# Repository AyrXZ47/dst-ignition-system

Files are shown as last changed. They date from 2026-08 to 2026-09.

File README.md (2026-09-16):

# 🚀 DST Ignition System




A solid-state, remote ignition system designed for experimental rocketry. Built for the Dragons Space Team to safely and reliably ignite rocket motors (like Estes Viking) using electronic matches.

## 🧠 System Architecture
* **Microcontroller:** Raspberry Pi Pico (RP2040)
* **Firmware:** Rust 🦀 with Embassy — **planned, not implemented yet** (see [Hardware status](#-hardware-status))
* **Telemetry & Comms:** LoRa (SX1278 RA-02, single transceiver — TX/RX role is firmware-side, half-duplex)
* **Power Switching:** Logic-Level N-Channel MOSFET (AOD4184A)

## 📂 Repository Structure
* `/hardware/`: KiCad project files (Schematics and PCB layouts).
* `/src/`: Rust source code for the RP2040 firmware.
* `/docs/`: Pinout diagrams, component datasheets, and operation manuals.

## 🛠️ Getting Started
### Firmware (Rust)
⚠️ **Not available yet.** The `src/` directory is empty: the Rust/Embassy firmware is planned but has not been written. The steps below are reserved for when it lands:

1. Install Rust and the `thumbv6m-none-eabi` target:
   `rustup target add thumbv6m-none-eabi`
2. Install `elf2uf2-rs` for easy flashing:
   `cargo install elf2uf2-rs --locked`
3. Build and run: `cargo run --release`

### Hardware
Open the project in KiCad 10.x (KiCad 9.x also fine) located in the `/hardware/` directory.

## 📋 Hardware status

Schematics and PCB live in `/hardware/Kicad/ignition-system/`. Current status
(wave 3, in progress — see [`docs/design-notes.md`](docs/design-notes.md) for
the full design reference):

* **Schematic:** RP2040 (Pico) + TP4056 Li-ion charger (TEMP via external NTC 10k B3950, TH1) + AOD4184A N-MOSFET ignition switch + SX1278 RA-02 socket (2× 1×08 headers: SPI + control rows) + I2C display + status LEDs + master power switch SW3 (battery → SW3 → VSYS; the pack charges with the board off). ERC: 0 errors / 0 warnings.
* **PCB:** placement in progress, **not routed** (agentes solo verifican con kicad-cli). DRC findings pending wave-3 fixes; see design-notes §5.
* **Firmware:** `src/` is empty; no Rust/Embassy code exists yet.
* **Next:** wave 2 SPICE validation of the MOSFET gate margin (3.3V vs Vto 2.61V).

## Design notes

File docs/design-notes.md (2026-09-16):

# Design Notes — DST Ignition System

> Referencia de diseño del sistema de ignición remota para cohetería
> experimental (Dragons Space Team).
> Fuentes: netlist exportado de `hardware/Kicad/ignition-system/ignition-system.kicad_sch`
> (2026-08-14, `kicad-cli sch export netlist`), `DRC.rpt`, y decision log en
> `.workflow/plan.md`. Estado: **wave 1 en curso** (fixes del esquemático en
> manos del humano, ver §3).

## 1. Topología

Sistema de ignición por MOSFET de lado bajo, alimentado por LiPo 1S y con
enlace de radio LoRa/nRF24:

```
                ┌────────────────────────────────────────────────┐
 USB ◄────────► │ Raspberry Pi Pico (RP2040)                     │
                │                                                │
                │  GPIO13  BTN_FIRE  ← SW1 (botón)               │
                │  GPIO15  IGNITION_GATE → R11 220Ω → G AOD4184A1│
                │  GPIO10/11/12 LEDs LINK / MODO / ARMADO        │
                │  GPIO26  ADC_Bateria ← divisor R5/R6 (10k/10k) │
                │  GPIO4/5 I2C (SDA/SCL) → Display1              │
                 │ GPIO16-19 SPI + GPIO20/21 → socket RA-02       │
                └───────┬─────────────────────────────────┬──────┘
                        │ VSYS (batería)                  │ 3V3
                ┌───────▼────────┐               ┌────────▼─────────┐
                │ TP4056 (carga) │               │ Display1 (I2C)   │
                │ CE → VBUS      │               │ 1x04, 2.54mm     │
                 │ TEMP → TH1 NTC │               └──────────────────┘
                 └───────┬────────┘
                         │ BATP (celda + BAT del TP4056)
                 ┌───────▼────────┐               ┌──────────────────┐
                 │ InBatt1 (JST)  │               │ AOD4184A1        │
                 │ LiPo 1S(PCM)   │               │ D ◄─ IGNITOR1.2  │
                 └───┬────────────┘               │ G ◄─ R11 ← GPIO15│
                     │ SW3 (SPDT)                 │ S → GND (low-side│
                     └─► VSYS ──► SW2.1/2.2 ──► IGNITOR1.1 (e-match)
                                       IGNITOR1 = terminal 5.0mm (1x02)
```

Flujo de disparo: `BTN_FIRE` (SW1) → GPIO13; firmware activa `IGNITION_GATE`
(GPIO15) → R11 220Ω → gate del AOD4184A1 → conduce → cierra el circuito del
ignitor (IGNITOR1) contra GND. El flujo de potencia de la placa: celda
(InBatt1) → nodo BATP (compartido con el pin BAT del TP4056) → SW3 → VSYS.
SW3 es el switch maestro de la placa: abierto = Pico/LEDS/divisor/ignitor
sin tensión (consumo ~0), cerrado = normal; la carga funciona con la placa
apagada (VBUS del pin 40 del Pico → TP4056 → BATP → celda, sin pasar por SW3).
SW2 (SPDT) conecta la línea del ignitor a VSYS (ON) o la ata a GND (seguro/descarga, línea sin fuente detrás).

## 2. Mapa de pines RP2040 (Raspberry Pi Pico)

Fuente: netlist exportado del esquemático (pad → net). Los GPIO se numeran
según el pinout estándar del Pico.

| Pad Pico | GPIO | Net | Función |
|---|---|-----|---|
| 6 | GPIO4 | SDA | Display I2C |
| 7 | GPIO5 | SCL | Display I2C |
| 14 | GPIO10 | LED_LINK | LED azul de enlace (R1 330Ω) |
| 15 | GPIO11 | LED_MODO | LED amarillo de modo (R2 330Ω) |
| 16 | GPIO12 | LED_ARMADO | LED rojo de armado (R3 330Ω) |
| 17 | GPIO13 | BTN_FIRE | Botón de disparo (SW1) |
| 20 | GPIO15 | IGNITION_GATE | Gate del MOSFET vía R11 220Ω |
| 21 | GPIO16 | MISO | SPI socket LORA RA-02 (fila LORA-Sx1278(B)) |
| 22 | GPIO17 | NSS | SPI CS (LORA-Sx1278(B)) |
| 24 | GPIO18 | SCK | SPI (LORA-Sx1278(B)) |
| 25 | GPIO19 | MOSI | SPI (LORA-Sx1278(B)) |
| 26 | GPIO20 | RST | Reset (LORA-Sx1278(A), fila de control) |
| 27 | GPIO21 | DIO0 | IRQ (LORA-Sx1278(A)) |
| 31 | GPIO26/ADC0 | ADC_Bateria | Medición de batería (divisor R5/R6) |
| 3, 8, 13, 18, 23, 28, 38 | — | GND | Tierra |
| 36 | — | 3V3 | Alimentación 3.3V |
| 39 | — | VSYS | Alimentación del Pico (batería) |
| 40 | — | VBUS | USB; alimenta el CE del TP4056 |

Sin conectar (disponibles para ola 2/3): GPIO0-3, GPIO6-9, GPIO14, GPIO22,
GPIO27/ADC1, GPIO28/ADC2, AGND, ADC_VREF, RUN, 3V3_EN.

Nota radio: LORA-Sx1278(A) y LORA-Sx1278(B) son una ÚNICA radio — el SOCKET
físico del módulo SX1278 RA-02 (2 filas de 8 agujeros, un borde por cara del
módulo de 17×16 mm). Fila A = control (GND, GND, 3V3, RST, DIO0); fila B =
SPI (NSS, MOSI, MISO, SCK); DIO1–DIO5 quedan sueltos sin conectar. El rol
TX/RX es puro firmware: transceptor half-duplex, un módulo por placa.

## 3. Decisiones de diseño

Del decision log de `.workflow/plan.md` (wave 1):

- **CE del TP4056 → VBUS (pin 8), no al net "VCC".** El net VCC no tiene
  fuente (ERC `power_pin_not_driven`). El pin 8 queda alimentado por VBUS, que
  viene del USB del Pico. *Estado: fix del humano en curso (GUI).*
- **TEMP del TP4056 (pin 1) va a GND a través de TH1** (NTC 10k B3950, header
  1x02; el NTC se pega a la celda, V lo confirma para 2026-09-15b). Revoca la
  nota wave 1 de "TEMP→GND": TEMP recupera su función térmica (ventana
  ≈ 0–45 °C); la protección eléctrica de la celda vive en el PCM integrado.
- **Labels DIO1-DIO5 eliminados.** Colgaban sin destino en el esquemático; si
  se necesitan en ola 2/3, se re-añaden con propósito concreto.
- **Human-in-the-loop como modelo de trabajo** (adaptación de AGENTS.md a
  hardware): el humano edita KiCad en GUI; los agentes planifican, verifican
  con `kicad-cli`, documentan y simulan. Los fixes de wave 1 los aplica el
  humano (~5 min de clics).
- **SW3 = switch maestro en serie entre BATP y VSYS** (nodo BATP: InBatt1.1 +
  pin BAT del TP4056). La carga funciona con la placa apagada (VBUS del pin 40
  del Pico → TP4056 → BATP → celda, aguas arriba del switch); con SW3 abierto
  el consumo es ~0. El pin suelto del SPDT queda sin conectar (nunca a GND:
  un interruptor de potencia a tierra cortocircuita el pack al accionarlo).
  Hay un PWR_FLAG en VSYS (anotación KiCad para satisfacer el ERC del switch
  de potencia, sin efecto eléctrico).
- **Disparo low-side**: el ignitor (J1) va entre la alimentación conmutada por
  SW2 y el drenador del MOSFET; fuente a GND. Pull-down R7 10k en el gate.
- **Divisor de batería**: VSYS → R5 10k → ADC_Bateria → R6 10k → GND.

## 4. BOM preliminar

Extraído del netlist exportado (29 referencias, 2026-09-16). Pendiente de confirmar
valores de display/módulos con el humano.

| Ref | Valor | Footprint | Función |
|-----|---|---|---|
| RaspberryPi_Pico1 | Raspberry Pi Pico (RP2040) | Module: Pico común | MCU |
| ModuloDeCarga1 | TP4056-42-ESOP8 | SOIC-8-1EP 3.9x4.9mm | Cargador Li-ion 1S |
| AOD4184A1 | NMOS (Vto≈2.61V, Ron≈5.8mΩ) | TO-252-2 | Interruptor de ignición |
| C1, C2 | 10µF | 0805 | Desacople |
| R1, R2, R3 | 330Ω | 0805 | LEDs LINK/MODO/ARMADO |
| R4 | 2.2kΩ | 0805 | PROG del TP4056 |
| R5, R6 | 10kΩ | 0805 | Divisor ADC_Bateria |
| R7 | 10kΩ | 0805 | Pull-down del gate |
| R8, R9 | 1kΩ | 0805 | LEDs STDBY/CHRG del cargador |
| R11 | 220Ω | 0805 | Serie al gate |
| BLED1, YLED1, RLED1 | LED | 0805 | Estado: enlace/modo/armado |
| CHRG1, STDBY1 | LED | 0805 | Estado de carga |
| Display1-SSD1306 | SSD1306 (conector 1x04) | PinHeader 2.54mm | Display I2C |
| InBatt1 | Conector 1x02 | JST PH 2.0mm | Batería LiPo 1S (≥500mAh: pulso de ignición ~2.7A) |
| IGNITOR1 | Terminal 1x02 | Screw_Terminal_01x02 5.0mm | Ignitor/e-match |
| LORA-Sx1278(A), (B) | Conector 1x08 | PinHeader 2.54mm | SOCKET del módulo SX1278 RA-02: fila control (A) + fila SPI (B) — 1 radio por placa |
| TH1 | NTC 10k B3950 | PinHeader 1x02 | Sonda térmica del TEMP del TP4056 (pegada a la celda) |
| SW1 | Pulsador | PinHeader 1x02 | BTN_FIRE |
| SW2 | SPDT | PinHeader 1x03 | Selector de ignitor: VSYS / GND |
| SW3 | SPDT | PinHeader 1x03 | Switch maestro de la placa (BATP ↔ VSYS) |

## 5. Estado del PCB

`hardware/Kicad/ignition-system/ignition-system.kicad_pcb` (KiCad 10.0):

- **Colocación en progreso** (humano, GUI, 2026-09-16): footprints colocados
  en tablero; sin conectar.
- **Ruteo: pendiente** (lo hace el humano en la GUI; los agentes solo
  verifican con `kicad-cli pcb drc`).
- **DRC 2026-09-16: 98 hallazgos** = 32 violaciones + 66 pads sin conectar
  (consecuente con un board sin rutear). Desglose de violaciones:
  `drill_out_of_range` ×6, `hole_clearance` ×8, `hole_to_hole` ×3,
  `copper_edge_clearance` ×2, `shorting_items` ×6, `items_not_allowed` ×2,
  `silk_over_copper` ×31, `silk_overlap` ×15, `silk_edge_clearance` ×10,
  `solder_mask_bridge` ×6, `lib_footprint_mismatch` ×9.
  ⚠️ Las 6 `drill_out_of_range` del TP4056 REGRESARON: el árbol integrado
  tiene `"min_through_hole_diameter": 0.3` (línea 161 del .kicad_pro) —
  el fix de T6 (0.2) se revirtió en la integración/fusión del .kicad_pro.
  Reportado a V; corregir con el humano en GUI antes de seguir el ruteo.
- ERC: **0 errores / 0 warnings** (2026-09-16, tras H7b/H8/H9 del humano).

## 6. Pendientes y riesgos

- **Margen de gate del AOD4184A1**: Vto≈2.61V contra 3.3V lógicos → Vgs−Vto
  ≈ 0.7V. Validar por SPICE en ola 2 (modelo en `hardware/Kicad/ignition-system/Local Spice/AOD4184A.lib`);
  si no conduce suficiente, driver de gate o MOSFET con Vto menor. También:
  slew rate con R11=220Ω y picos en el pull-down R7.
- **Switch maestro SW3 + carga**: BATP (celda + pin BAT del TP4056) → SW3 →
  VSYS; la carga funciona con la placa apagada (VBUS pin 40 → TP4056 → BATP,
  sin pasar por SW3); con SW3 abierto el consumo del sistema es ~0 (reemplaza
  al viejo "BAT+ (VSYS)" directo). Colocar cerca del borde, aparte del
  conector InBatt, con huella accesible de mano enguantada.
- **NTC TH1**: pegar físicamente la sonda B3950 a la celda (cinta Kapton) y
  ruta corta InBatt→TH1 en el ruteo; ventana térmica ≈ 0–45 °C.
- **Firmware**: `src/` está vacío; el Rust/Embassy prometido en el README aún
  no existe (ver README, §Estado del hardware).
- **Ignitor/e-match — RESUELTO 2026-09-02 (medido, lote n=10)**: R_min/R_typ/
  R_max = **0.8 / 0.93 / 1.1 Ω** (2 multímetros, spread ≤0.3Ω, lote
  consistente). R_wire del cableado no medido: estimado **0.2Ω** conservador.
  Fase B destructiva: 4/4 ignitores disparados con pila 3V vía amperímetro;
  rango 200mA en OVERLOAD → I_fire > 200mA real (la lectura "0.01A" del rango
  10A se descarta como artefacto de display: el burst dura ms, el DMM muestrea
  ~3/s; a 10mA con 0.93Ω habría solo 0.1mW — físicamente imposible).
  **Chequeo de margen**: `I_worst = 3.3 / (R_max + R_wire + 0.034)` =
  3.3 / (1.1 + 0.2 + 0.034) ≈ **2.47A ≥ 1.1A** (margen 2.25×). Nominal
  3.6V → 2.70A. P ignitor ≈ 6.7W por pulso; P MOSFET ≈ 0.21W por pulso
  (trivial para DPAK). **Cierra la condición del REPORT.md de wave 2:
  veredicto (a) CONFIRMADO con datos reales** — AOD4184A se queda, sin driver
  ni cambio de MOSFET. Fuente: decision log de `.workflow/plan.md`
  (entrada 2026-09-02).
- **Radio — RESUELTO 2026-09-15**: es LoRa SX1278 RA-02. No hay dos radios:
  LORA-Sx1278(A)/(B) son el socket físico del módulo (2 filas de 8); el rol
  TX/RX es puro firmware (transceptor half-duplex, un módulo por placa).
  DIO1–DIO5 del módulo quedan sueltos (sin conectar en el socket).
- **Display — modelo confirmado (2026-09-01)**: SSD1306 I2C sobre conector
  1x04; queda solo confirmar si el conector 1x04 basta (el 5º pin del
  SSD1306-A es VCC extra, opcional).

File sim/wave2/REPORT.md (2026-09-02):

# REPORT — Validación SPICE del disparo del ignitor (Wave 2 · Executor 3)

**Fecha:** 2026-09-01 · **Simulador:** ngspice-45 (`/run/current-system/sw/bin/ngspice`)
**Netlist:** `sim/wave2/ignition-sim.cir` (autocontenido, modelo VDMOS inline)
**Reproducir:** `bash sim/wave2/run.sh` → salidas en `sim/wave2/out/` (log + `.raw` por caso)

## Veredicto: **(a) OK para rutear con el AOD4184A**

El AOD4184A conduce el ignitor con holgura a Vgs≈3.3V en todos los casos
simulados, incluido el peor caso (LiPo descargada 3.3V + ignitor 2Ω):

| Caso | Ignitor | VSYS | Id disparo | Vds | Rds(on) eff. | P MOSFET | Criterio ≥1.5A |
|---|---|---|---|-----|---|---|---|
| 1 (nominal) | 1.5Ω | 3.6V | **2.347 A** | 79.5 mV | 33.9 mΩ | 0.19 W | ✓ +0.85A |
| 2a (margen alto) | 2Ω | 3.6V | **1.770 A** | 59.5 mV | 33.6 mΩ | 0.11 W | ✓ +0.27A |
| 2b (margen bajo) | 1Ω | 3.6V | **3.480 A** | 120.2 mV | 34.5 mΩ | 0.42 W | ✓ +1.98A |
| 2c (peor caso) | 2Ω | 3.3V | **1.623 A** | 54.4 mV | 33.5 mΩ | 0.09 W | ✓ +0.12A |

Criterio del brief: corriente ≥ 1 A del ignitor + 0.5 A de margen → **1.5 A**.
El peor caso simulado (2c) da 1.62 A — cumple, pero es la esquina justa; ver
"Condiciones" más abajo.

No hace falta driver de gate ni cambiar de MOSFET: la zona de potencia puede
rutearse tal cual está el esquemático (GPIO15 → R11 220Ω → gate, R7 10k
pull-down, low-side).

## Caso 3 — Barrido DC Id vs Vgs (carga fija 1.5Ω, VSYS 3.6V)

| VGPIO (pre-R11) | Id | Nota |
|---|-----|---|
| 2.6 V | 84 mA | inicio de conducción (Vto=2.61 del modelo) |
| 2.7 V | 350 mA | |
| 2.8 V | 1.02 A | **VGPIO=2.80V ⇔ 1 A** (gate real ≈2.74V) |
| 2.9 V | 2.07 A | |
| 3.0–3.3 V | 2.30–2.35 A | limitado por la carga (no por el FET) |

El divisor R11/R7 (220Ω/10k) solo cuesta 71 mV: el gate reposa a 3.229V con
GPIO a 3.3V. La curva es empinada justo en la zona de trabajo (0.4V de
VGPIO pasan de 84 mA a 2.3 A), lo que hace el diseño tolerante al spread de
Vto **siempre que Vgs final quede claramente por encima del codo** — y queda:
3.23V vs codo ~2.8V.

## Caso 4 — Slew del gate (R11 220Ω + Ciss=1365pF del modelo)

Con un flanco GPIO deliberadamente lento de 1 µs (peor caso realista; el
RP2040 real conmuta en ns):

- **t al 90% de Id: 2.78 µs** desde el inicio del flanco (t90_id=102.78µs,
  pulso en t=100µs).
- t al 90% de Vgs: 3.02 µs. La corriente se adelanta al gate porque cruza el
  codo antes de que el gate termine de subir.
- Corriente estabilizada (±0.1%): ~10 µs. Sin overshoot (Id sube monotónico
  hasta 2.347 A).

Para un ignitor que necesita pulsos de ~ms, el retardo de µs es irrelevante.
R11=220Ω está bien; incluso 1kΩ seguiría siendo sobrado.

## Potencia

- **MOSFET:** peor caso continuo simulado 0.42 W (ignitor 1Ω). En el uso real
  el pulso es de ms → irrelevante para un DPAK (TO-252) incluso sin cobre
  térmico extra. P = Id²·Rds con Rds_eff≈34mΩ a Vgs=3.23V (el "Ron=5.8m" del
  modelo es a Vgs=10V; a 3.3V el modelo da ~34mΩ, coherente con Vto=2.61).
- **Ignitor (referencia):** 8.3 W durante el pulso en el caso nominal — es lo
  que dispara el e-match, no afecta al MOSFET.

## Condiciones y límites del veredicto

1. **El veredicto vale si el ignitor real pide ≤1.1 A.** El peor caso (2c)
   da 1.62 A: si al medir el e-match real su corriente de disparo supera
   ~1.1 A, el margen de 0.5 A ya no se cumple y tocaría pasar a (b) driver
   de gate o (c) MOSFET con Vto<2V. **Acción: medir la resistencia y
   corriente del ignitor real al recibirlo** (es la única variable no
   controlada).
2. **Spread de Vto (estimación analítica, no simulada):** si una unidad real
   tiene Vto=3.0V (peor caso de spread), Rds≈1/(Kp·(Vgs−Vto))≈1/(70·0.23)≈
   62mΩ → Id≈3.6/(1.5+0.062)≈2.30A a 1.5Ω. Sigue sobrado: la carga domina,
   no el FET.
3. Modelo Bordodynov inline verificado en ngspice-45 sin warnings
   (`mfg`, `Ron`, `Qg` se aceptan como parámetros informativos).
   Fuente: `hardware/Kicad/ignition-system/Local Spice/AOD4184A.lib`.

## Quirks de ngspice-45 encontrados (para quien repita esto)

- `meas` **no** acepta vectores de dispositivo tipo `@m1[id]` (devuelve 0 o
  "out of interval"). Usar la corriente de la fuente: `let idd = -i(vsys)`
  (VSYS solo alimenta el ignitor, así que es exactamente Id).
- `wrdata` escribe **pares (x, y) por vector**: con 3 vectores salen 6
  columnas (t, y1, t, y2, t, y3). No confundir la columna y2 con la x.
- `print` con texto literal lanza `PPerror`; usar `echo "..."`.
- Los resultados de `meas` mueren con `destroy all`/`reset`: si un `WHEN`
  necesita un valor medido antes, re-medirlo en el mismo plot (hecho así en
  el caso 4).

## Archivos

- `ignition-sim.cir` — netlist con los 4 casos (2a/2b/2c como caso 2) en un
  solo `.control`, orquestados con `alterparam`+`reset`.
- `run.sh` — corre ngspice en batch, tedea a `out/ngspice.log` y falla si no
  llega al caso 4 (chequeo ejecutable mínimo).
- `out/` — `ngspice.log` + un `.raw` ASCII por caso (case1, case2a/b/c,
  case3, case4).

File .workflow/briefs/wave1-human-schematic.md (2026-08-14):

# Brief: Wave 1 · Humano (GUI de KiCad)

> Este brief lo ejecuta el HUMANO en la GUI de KiCad — no un agente.
> Son ~5 minutos de clics. Los agentes verifican después con kicad-cli.
> Si una instrucción no encaja con lo que ves, PARA y reporta al planner.

## Task

Abrir `hardware/Kicad/ignition-system/ignition-system.kicad_sch` en KiCad y
hacer 3 correcciones para dejar el ERC en 0 errores. NO hagas nada más.

### Fix 1 — CE del TP4056: de "VCC" a "VBUS"

El pin 8 (CE) de `ModuloDeCarga1` (el TP4056) está conectado a un símbolo de
potencia rotulado **"VCC"** que no tiene ninguna fuente (ERC:
`power_pin_not_driven`). El CE es enable activo alto: debe ir al 5V del bus
USB.

**Cómo hacerlo (elegí la opción que te resulte más natural):**
- **Opción A (recomendada):** clic derecho sobre el símbolo de potencia
  "VCC" que cuelga del pin CE → *Properties* → cambia el campo *Value* de
  `VCC` a `VBUS` → OK. (El símbolo de potencia es una etiqueta: renombrar
  el Value re-etiqueta el net. VBUS ya existe y está alimentado por el
  Pico pin 40 y C2.)
- **Opción B:** borra el símbolo VCC y coloca un nuevo símbolo de potencia
  `VBUS` (tecla `P` → busca "VBUS" → colócalo sobre el pin CE).

**Verificación visual:** el net del pin 8 ahora debe decir `VBUS`, y debe
haber al menos otro componente en ese net (el Pico pin 40 y C2).

### Fix 2 — TEMP del TP4056: a GND

El pin 1 (TEMP) de `ModuloDeCarga1` está sin conectar (ERC:
`pin_not_connected` + `pin_not_driven`). En v1 no hay NTC en el BOM, así que
lo llevamos a GND (desactiva el monitoreo de temperatura; la celda carga a
1A fijo — decisión ya tomada en el plan, con `ponytail:` comentario: si
algún día usas LiPo con NTC, añade divisor TEMP en ola 3).

**Cómo hacerlo:** coloca un símbolo de potencia `GND` (tecla `P` → busca
"GND") tocando el extremo del pin 1 de ModuloDeCarga1. Si el pin no termina
en un punto fácil, traza un pequeño wire desde el pin hasta el símbolo GND.

### Fix 3 — Borrar labels DIO1-DIO5

Hay 5 global labels colgando sin conexión (ERC: `label_dangling`). No tienen
destino. Bórralos (clic en cada label → `Supr`):

| Label | Coordenadas (mm) |
|---|---|
| DIO1 | (207.01, 76.20) |
| DIO2 | (207.01, 78.74) |
| DIO3 | (207.01, 81.28) |
| DIO4 | (242.57, 78.74) |
| DIO5 | (242.57, 76.20) |

## Definition of done

- El símbolo de potencia del pin CE (pin 8 del TP4056) dice `VBUS`.
- El pin TEMP (pin 1 del TP4056) tiene un GND tocando su extremo.
- Los 5 labels DIO1-DIO5 ya no existen en la hoja.
- Guardas el esquemático (Ctrl+S) y KiCad no reporta errores al guardar.
- **NO** has tocado nada más (ni el PCB, ni footprints, ni valores, ni el
  DRC del PCB).

## Files you own

- `hardware/Kicad/ignition-system/ignition-system.kicad_sch`
  (lo edita la GUI de KiCad; tú solo guardas).

## Files forbidden

- `hardware/Kicad/ignition-system/ignition-system.kicad_pcb` y `*.kicad_pro`
- `hardware/Kicad/ignition-system/DRC.rpt` y `Local Spice/*`
- `docs/*`, `README.md`, `.gitignore`, `.workflow/*`, `AGENTS.md`

## Read first

- `.workflow/plan.md` → Decision log: las 3 decisiones ya están tomadas
  (CE→VBUS, TEMP→GND, DIO eliminados). No las re-discutas.

## Verify command

NO ejecutes comandos: el executor-1 correrá la verificación headless después
de que tú guardes y commitees. Para tu tranquilidad, si quieres autocomprobar
antes de commitear, corre en una terminal:

```bash
kicad-cli sch erc --output /tmp/opencode/erc-human.rpt \
  hardware/Kicad/ignition-system/ignition-system.kicad_sch
grep -E "Errors [0-9]+" /tmp/opencode/erc-human.rpt   # esperado: Errors 0
```

## Commit

- Conventional commit, una línea, imperativo. Ejemplo:
  `fix: point tp4056 ce to vbus and tie temp to gnd`
  (o `fix: remove dangling dio labels` si haces commits separados — 1 por
  cambio lógico está bien, pero uno solo también vale).
- Commit AND push a tu rama `wave1-human` (o a `main` si el integrador lo
  acordó así). Nunca forces push, nunca toques ramas de otros.

## Report back

- Qué opción usaste en el Fix 1 (A o B) y cualquier cosa rara que vieras.
- Si el ERC no dio 0 tras tus cambios, el texto exacto de los errores que
  queden.

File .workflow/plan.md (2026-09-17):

# Plan: DST Ignition System — diseño hardware listo para fabricación

> Single source of truth for the work. Committed, survives any session.
> ONLY the next wave is detailed (rolling plan). When a session dies, a new
> instance resumes from this file — never from memory.

## Goal

Sistema de ignición remota para cohetería experimental (Dragons Space Team):
esquemático y PCB (RP2040 + TP4056 + MOSFET AOD4184A + 2×LoRa/nRF24 + display
I2C) listos para fabricar. "Done" = ERC 0 errores, DRC 0 errores, disparo del
ignitor validado por simulación SPICE, y Gerbers + BOM generados.

## Stack & constraints

- KiCad 8.x/10 (formatos `.kicad_sch` / `.kicad_pcb` = S-expression, texto).
- Verificación headless: `kicad-cli` v10.0.5 (sch erc, sch export netlist,
  sch export pdf, pcb drc, pcb export gerbers).
- Modelo SPICE local: `hardware/Kicad/ignition-system/Local Spice/AOD4184A.lib`
  (VDMOS, Vto=2.61V, Ron=5.8mΩ).
- Simulación: ngspice-45 (instalado globalmente 2026-09-01, gate de la ola 2
  desbloqueado). Auxiliares del humano: `spice-find` / `spice-get`
  (kicad-spice-library, ~50k modelos; `spice-get aod4184a` extrae un modelo
  saneado y validado en ngspice a `localSpice.lib` del proyecto).
- Ignitor/e-match estándar (~1-2Ω, ~1A) — pendiente confirmar con el humano.
- Licencias: hardware CERN-OHL-P-2.0, software Apache-2.0.
- **Modelo de trabajo: HUMAN-IN-THE-LOOP (adaptación del flujo AGENTS.md a
  hardware).** El humano es el único que edita archivos en la GUI de KiCad
  (esquemático y PCB). Los agentes: planifican, instruyen paso a paso,
  verifican con kicad-cli, documentan, simulan. Ningún agente "edita por
  texto" archivos KiCad salvo los cambios quirúrgicos explícitamente
  marcados como seguros; y siempre con verificación headless posterior.
- Regla ponytail: mínimo cambio que funciona; no añadir drivers/partes hasta
  que la simulación demuestre que hacen falta.

## Waves

| Wave | Focus | Status |
|---|---|---|
| 1 | Esquemático limpio: ERC 0, fixes TP4056 (CE→VBUS, TEMP), labels DIO, artefactos docs | [x] integrated (ERC 0 verificado 2026-08-18) |
| 2 | Validación de potencia por SPICE (gate 3.3V vs Vto 2.61V, disparo del ignitor) | [x] audited 2026-09-01 (APPROVED WITH EXCEPTIONS, ver `.workflow/audits/wave2.md`) |
| 3 | PCB: reglas, planos de cobre, ruteo (HUMANO en GUI), DRC 0 | [x] audited 2026-09-16 (APPROVED WITH EXCEPTIONS menores, ver `.workflow/audits/wave3.md` — DRC 0 errores/0 unconnected, ERC 0) |
| 4 | Release: Gerbers, BOM, PDF final, security-audit | [x] gerbers+BOM exportados 2026-09-16 (`hardware/fab/ignition-system-jlcpcb.zip`) — falta: pedido JLCPCB + security-audit de release |

> Status legend: planned → in-flight → integrated → audited → done.
> Update after each step, by whoever ran the step.

---

## Wave 1 (current)

### Cómo se ejecuta esta ola (orden estricto)

1. **Humano (GUI):** hace los 3 fixes del esquemático siguiendo el brief
   manual `wave1-human-schematic.md` — son ~5 minutos de clics.
2. **Executor-1 (agente):** verifica el trabajo del humano con kicad-cli
   (ERC 0 + netlist correcto), regenera el PDF y lo commitea.
3. **Executor-2 (agente, puede correr en paralelo):** documentación,
   .gitignore, README — texto puro, no toca KiCad.
4. **Integrador:** merge en el orden indicado + verificación final.

### File ownership map

| File/glob | Owner |
|---|---|
| `hardware/Kicad/ignition-system/ignition-system.kicad_sch` | HUMANO (GUI) — ediciones en wave 1 |
| `hardware/Kicad/ignition-system/ignition-system.kicad_pcb` | prohibido en wave 1 (ola 3, GUI) |
| `docs/ignition-system.pdf` | executor-1 (regenerado, verificado) |
| `docs/design-notes.md` (nuevo), `README.md`, `.gitignore` | executor-2 |
| `hardware/Kicad/ignition-system/Local Spice/*`, `.history/`, `DRC.rpt`, `*.lck`, `*.kicad_pro` | prohibido |

### Tasks

- [ ] H1: Humano (GUI): CE del TP4056 → net VBUS (el "VCC" no tiene fuente);
      TEMP (pin 1) → GND; borrar labels DIO1-DIO5 →
      brief: `.workflow/briefs/wave1-human-schematic.md`
- [ ] T1: executor-1: verificar (ERC 0 + netlist VBUS/GND sin VCC huérfano),
      regenerar `docs/ignition-system.pdf` → brief: `.workflow/briefs/wave1-executor-1.md`
- [ ] T2: executor-2: `docs/design-notes.md` (topología, mapa de pines,
      decisiones, BOM, estado PCB), `*.lck` a `.gitignore`, README →
      brief: `.workflow/briefs/wave1-executor-2.md`

### Integration plan

Orden: **executor-2** (docs, sin dependencias) y **trabajo del humano** en
paralelo; luego **executor-1** verifica/regenera el PDF; por último merge e
integración. Ramas: humano commitea en su rama `wave1-human` (o en main si
prefiere; el integrador decide), executor-1 → `wave1-executor-1`,
executor-2 → `wave1-executor-2`.

```bash
# 1. merge wave1-executor-2 -> main   (docs, sin conflicto)
# 2. humano: fixes en GUI + commit en wave1-human (o main)
# 3. executor-1: verifica ERC + regenera PDF (tras el fix humano)
# 4. merge humano (wave1-human o main) + wave1-executor-1 -> main
# 5. verificación final en el árbol integrado:
kicad-cli sch erc --output /tmp/opencode/erc-final.rpt \
  hardware/Kicad/ignition-system/ignition-system.kicad_sch   # "Errors 0"
```

En conflicto: STOP y reportar. Nunca resolver con criterio propio.

### Audit gate

Correr `.workflow/audit-checklist.md` en el árbol integrado. Específico:

- Solo se modificaron archivos del ownership map.
- ERC en el árbol integrado: 0 errores (evidencia: erc-final.rpt).
- Netlist integrado: net `VBUS` incluye `ModuloDeCarga1.8`; net `GND`
  incluye `ModuloDeCarga1.1`; el net "VCC" huérfano ya no existe.
- `docs/design-notes.md` existe y cubre: topología, mapa de pines, decisiones.
- El PDF regenerado es más reciente que el commit `0df3d5b`.

---

## Wave 2 (current — next wave)

### Por qué ANTES del ruteo (orden crítico)

El AOD4184A tiene Vto=2.61V y el gate viene de 3.3V → Vgs−Vto≈0.7V. Si el
MOSFET no conduce suficiente corriente para el ignitor (~1-2Ω, 1A), hay que
cambiar de MOSFET o añadir un driver de gate — y ESO cambia el ruteo de toda
la zona de potencia. Rutear sin validar = re-spin de 2 semanas en China.
SPICE primero; el ruteo (ola 3) no empieza hasta que esta ola dé verde.

### Qué se simula (y qué NO)

- **NO** se simula la placa completa ni el RP2040: un GPIO digital es una
  fuente pulsada 0→3.3V; el Pico no entra en SPICE.
- **NO** se simula el TP4056 (cargador lineal, no crítico para el disparo).
- **SÍ** se simula el subcircuito de ignición: fuente pulsada 3.3V → R11 220Ω
  → gate (R7 10k a GND) → AOD4184A (modelo local en `Local Spice/`) → ignitor
  (~1-2Ω) entre VSYS y drain. Corriente de disparo, caída en el MOSFET,
  slew rate, requisito mínimo de corriente del ignitor.

### File ownership map

| File/glob | Owner |
|---|---|
| `sim/wave2/*.cir`, `sim/wave2/*.cpp` (nuevos), informe | executor-3 |
| `hardware/Kicad/ignition-system/*` | prohibido para executor-3 (ni lectura requerida salvo el .lib y el .kicad_sch) |
| `hardware/Kicad/ignition-system/ignition-system.kicad_sch` | HUMANO, SOLO para H4 (borrar stubs; nada más) |
| `docs/design-notes.md` | prohibido salvo añadir §7 "Validación SPICE" (revisar con planner si hace falta) |

### Tasks

- [ ] H4 (humano, GUI, paralelo con executor-3): borrar los 4 stubs de cable
      sueltos junto a CHRG1/STDBY1 → ERC 0/0 (ver brief manual H4 en el
      decision log; causas y coordenadas documentadas 2026-09-01)
- [x] T3: Generar netlist SPICE del subcircuito de ignición, casos de test
      (corriente de ignitor a 3.3V, a 3.6V LiPo, con R11=220Ω), correr en
      ngspice, escribir informe con veredicto → brief:
      `.workflow/briefs/wave2-executor-3.md`
- Requisito: instalar ngspice — **hecho** (ngspice-45 global, 2026-09-01).

### Integration plan

- Executor-3 en rama `wave2-executor-3`; merge a `main`; revisar informe.
- Veredicto del informe = gate de la ola 3: si Vgs es insuficiente, el humano
  decide (driver vs MOSFET) y se ajusta el esquemático ANTES de rutear.

### Audit gate

- El informe existe, ngspice corrió (salida transitoria/dc adjunta), y el
  veredicto tiene números: corriente de ignitor, Vds, potencia disipada.

---

## Wave 3 (current — next wave)

### Objetivo

PCB listo para fabricar: reglas de board setup corregidas (executor-4),
placement + ruteo hechos por el HUMANO en GUI, DRC 0 errores, y datos
reales del ignitor incorporados (condición del audit de wave 2).

### Orden estricto

0. **H7b (humano, GUI) — el "H7 consolidar radio" fue ANULADO 2026-09-15**
   (diagnóstico corregido, ver decision log): LORA1+LORA2 son el SOCKET del
   RA-02 (17×16mm, 8 agujeros por borde del módulo; el wiring existente
   casa 1:1 con las filas físicas — fila A = LORA1, fila B = LORA2). Fix:
   completar el socket con los GND físicos de borde: LORA1 pin1→GND,
   LORA1 pin8→GND, LORA2 pin1→GND (DIO1-5 sueltos: el firmware solo usa
   DIO0). ERC 0/0. En el PCB: headers JUNTOS como socket (separación =
   medida real del módulo, filas en espejo). El rol TX/RX sigue por
   firmware.
0b. **H8 (humano, GUI) — NTC de carga (revierte parcialmente la decisión
    wave 1 TEMP→GND directo; el PCM va integrado en la celda):** en el
    esquemático, desconectar el pin 1 (TEMP) del ModuloDeCarga1 del GND y
    añadir un `Device:Thermistor_NTC` (Value: `NTC 10k B3950`) entre TEMP y
    GND; footprint: `PinHeader_1x02_P2.54mm_Vertical` (el NTC epoxy se suelda
    con sus dos patas al header, pegado con kapton a la superficie de la
    celda). Ventana térmica resultante ≈ 0–45°C de carga. ERC 0/0 + commit.
    En el PCB: el nuevo footprint cerca de InBatt (el sensor va al pack,
    no al aire). BOM +1 ítem.
0c. **H9 [rev 2026-09-15] (humano, GUI) — switch maestro del lado del
    CONSUMO, no de la batería** (comportamiento tipo teléfono: cargar con la
    placa apagada). Rewiring: el nudo InBatt pin1 ↔ TP4056 pin5 (BAT) queda
    SIEMPRE conectado (label `BATP`); desde ese nudo → SW3 pin2 → pin1 →
    VSYS. Así: switch abierto = Pico/divisor/LEDS/ignitor muertos, y USB
    enchufado = celda cargando igual. LEDs CHRG/STDBY siguen indicando
    (su alimentación es VBUS, aguas abajo del USB del Pico, no del switch).
    Drain con switch abierto: µA clínicamente cero (leak del TP4056 + PCM
    de la celda — ambos << autodescarga). El ítem de "para CARGAR hay
    que encender el switch" queda revocado. постановка PCB igual: cerca
    del borde. BOM +1 (ya hecho). ERC 0/0 + commit.

1. **T6 (executor-4):** board setup `min_through_hole_diameter` 0.3 → 0.2mm
   en `.kicad_pro` (JSON, clave `"design_settings.rules.min_through_hole_diameter"`,
   línea ~155) + DRC: las 6 violaciones `drill_out_of_range` del TP4056
   desaparecen. **ANTES de que el humano abra la GUI** (evita pisar el
   `.kicad_pro` con KiCad abierto).
2. **H5 (humano, mundo físico) — [x] HECHO 2026-09-02:** ignitores medidos
   (datos completos en decision log): R lote n=10 → min 0.8 / typ 0.93 /
   max 1.1Ω (2 multímetros). Fase B: 4/4 disparos con pila 3V, I > 200mA
   (rango 200mA en overload). Margen verificado: I_worst ≈ 2.47A ≥ 1.1A.
   **Condición del REPORT.md de wave 2: CERRADA — veredicto (a) confirmado.**
3. **T7 (executor-4):** incorporar los números reales a `docs/design-notes.md`
   (§6 ignitor) y re-chequeo de margen: `I_worst = 3.3/(R_max + R_wire + 0.034)`
   debe ser ≥ 1.1A (condición del informe SPICE). Si falla → ESCALAR al
   planner inmediatamente (revive veredicto b/c de wave 2).
4. **H6 (humano, GUI):** placement por bloques lógicos + ruteo →
   brief manual: `.workflow/briefs/wave3-human-routing.md`
5. **T8 (executor-4):** `kicad-cli pcb drc` loop hasta 0 errores y 0
   unconnected.

### File ownership map

| File/glob | Owner |
|---|---|
| `ignition-system.kicad_pcb` | HUMANO (GUI) — placement y ruteo |
| `ignition-system.kicad_sch` | HUMANO SOLO para H7b (3 GND socket RA-02), H8 (NTC al TEMP) y H9 (switch maestro SW3 — ver decision log 2026-09-15c) |
| `.kicad_pro` (SOLO la clave min_through_hole_diameter) | executor-4 (T6) |
| `docs/design-notes.md` (§ ignitor/estado PCB → T7 [hecho]; §2 pin map, §4 BOM, §6 nota radio → T9) | executor-4 |
| `docs/ignition-system.pdf` | executor-4 (T9: regenerado con kicad-cli tras H7b) |
| `ignition-system.kicad_sch` | — (definido arriba; la double-entrada anterior queda obsoleta) |
| `docs/design-notes.md` (§ ignitor/estado PCB → T7 [hecho]; §2 pin map, §4 BOM, §6 nota radio/NTC + estado PCB → T9) | executor-4 |
| `sim/wave2/*`, `.workflow/*` | prohibidos para executor-4 |

> Nota (práctica observada en `a9de791`): si la GUI de KiCad reordena el
> `.kicad_pro` al guardar, commitearlo como `chore(kicad):` separado.

### Integration plan

Rama única de executor: `wave3-executor-4` (worktree análogo a la ola 2).
El humano commitea `.kicad_pcb` directamente en main. Secuencia: T6 →
H5+T7 → H6 (ruteo) → T8 → DRC final en main:

```bash
kicad-cli pcb drc --output /tmp/opencode/drc-final.rpt \
  hardware/Kicad/ignition-system/ignition-system.kicad_pcb   # "Errors 0"
```

En conflicto: STOP y reportar.

### Audit gate

- DRC en main: 0 errores, 0 unconnected (evidencia: drc-final.rpt).
- Las 6 drill_out_of_range ya no existen.
- design-notes tiene los datos REALES del ignitor y el chequeo de margen.
- Archivo de auditoría `.workflow/audits/wave3.md` (cierra la excepción 2
  de wave 2: cada ola termina con su audit).

## Wave 4 (future — not detailed yet)

Gerbers + BOM + PDF final — 100% headless con kicad-cli (agente) +
`skills/security-audit` (release gate) + docs de operación.

---

## Decision log

| Date | Decision | Why |
|---|---|-----|
| 2026-08-14 | CE del TP4056 irá a VBUS, no al net "VCC" | ERC: `power_pin_not_driven`; el símbolo VCC no tiene fuente en el esquemático |
| 2026-08-14 | TEMP del TP4056 a GND en v1 | Sin NTC en el BOM; `ponytail:` — si se usa LiPo con NTC, añadir divisor en ola 3 |
| 2026-08-14 | Labels DIO1-DIO5 se eliminan | Cuelgan sin destino; si se necesitan en ola 2/3, se re-añaden con propósito |
| 2026-08-14 | `*.lck` a .gitignore | Archivos lock de KiCad abierto, ruido en git status |
| 2026-08-14 | Drill 0.2mm del TP4056 se corrige en ola 3 | Es problema del footprint/board setup, no del esquemático |
| 2026-08-14 | **Human-in-the-loop**: el humano edita en GUI, los agentes planifican/verifican/documentan/simulan | El ruteo y las ediciones visuales de KiCad no son automatizables de forma fiable por texto; 3 clics en GUI > cirugía de texto frágil (ponytail). Adaptación explícita de AGENTS.md a hardware |
| 2026-08-14 | **Wave 1 autorizada** por el humano — plan confirmado sin cambios; arranque inmediato | Las 3 decisiones (CE→VBUS, TEMP→GND, DIO fuera) fueron confirmadas |
| 2026-08-18 | **Wave 1 integrada** — ERC 0 (2 warnings de wire endpoint menores), PDF regenerado, docs/design-notes.md, README corregido (firmware indicado como planeado) | Commits 728ab0c, 1f5a174, e658fdf, 0875346 |
| 2026-08-18 | **Una placa, dos roles (RX/TX)** | El usuario confirma: un solo diseño con todas las secciones; al llegar de China una placa se arma como RX y otra como TX (diferente firmware/DNP según rol). Esto NO cambia el esquemático ni el ruteo: las secciones (radio, ignición, carga) ya existen en una placa |
| 2026-08-18 | **SPICE ANTES del ruteo** (ola 2 → ola 3) | Si el AOD4184A no conduce a 3.3V, cambia la zona de potencia y el ruteo entero; evitar re-spin |
| 2026-08-18 | `*.kicad_pro` prohibido en wave 1 | Los fixes de board setup (min hole) son de ola 3; mantener ola 1 mínima |
| 2026-09-01 | Designators renombrados con sufijo de chip: `LORA1-Sx1278`, `LORA2-Sx1278`, `Display1-SSD1306`, `RaspberryPi_Pico1-RP2040` (commit 40ce5ba) | Cierra 2 preguntas abiertas de design-notes §6: radio = LoRa SX1278, display = SSD1306. ERC re-verificado hoy: 0 errores / 2 warnings menores conocidos |
| 2026-09-01 | ngspice-45 + spice-find/spice-get instalados globalmente; ola 2 desbloqueada y lista para lanzar | Executor-3 usa el modelo local `Local Spice/AOD4184A.lib`; fallback: `spice-find aod4184a` + `spice-get aod4184a` (crea `localSpice.lib`) si el modelo local falla en ngspice |
| 2026-09-01 | **Wave 2 integrada** — merge `wave2-executor-3` (2c1a827) a main, sin conflictos. ERC integrado: 0 errores / 0 warnings (H4 humano cerró los 2 menores). Sim reproducida en ngspice-45: exit 0. Veredicto REPORT.md: (a) OK para rutear con AOD4184A, condición: medir ignitor real ≤1.1 A al recibirlo. Gate de la ola 3: VERDE | Merge 9c72979; commits a9de791 (kicad_pro humano) + 2c1a827 |
| 2026-09-01 | **Wave 2 in-flight**: worktree `../dst-ig-wave2-executor-3` creado, executor-3 lanzado por el humano | Plan de integración wave 2 sin cambios: merge `wave2-executor-3` → main al terminar |
| 2026-09-01 | **Auditoría wave 2: APPROVED WITH EXCEPTIONS** (`.workflow/audits/wave2.md`) — números del informe reproducidos por el auditor, ERC integrado 0/0, `.raw` byte-idénticos al re-corrida. Excepciones: (1) `a9de791` tocó `kicad_pro` fuera del map (side-effect GUI del humano, 1 línea, mitigado); (2) ola 1 sin archivo de auditoría formal — gates re-verificados aquí. Regla nueva: cada ola cierra con su audit file | Gate ola 3 VERDE con condición: medir ignitor real ≤1.1 A al recibirlo |
| 2026-09-01 | **Causa raíz de los 2 warnings ERC** (`unconnected_wire_endpoint`): 4 segmentos de cable sobrantes junto a CHRG1 (156.21, 171.45) y STDBY1 (156.21, 184.15) — restos de los labels DIO borrados en wave 1. Fix = tarea H4 (humano, GUI): borrar el wire horizontal desde el pin K (que ya tiene label VBUS encima) + el stub vertical de 2.54mm que cuelga hacia arriba, en cada LED | Los pines de los LEDs ya están conectados (K→VBUS por label, A→R8/R9); el alambrado sobrante sobra. Tras el fix: ERC objetivo 0 errores / 0 warnings |
| 2026-09-02 | **H5: ignitor real medido por el humano.** Lote n=10, 2 multímetros: R min 0.8 / typ 0.93 / max 1.1Ω (spread ≤0.3, lote consistente). Fase B: 4/4 disparados con pila 3V vía amperímetro; rango 200mA → OVERLOAD (I > 200mA real); la lectura "0.01A" del rango 10A se descarta como artefacto de display (el burst dura ms, el DMM muestrea ~3/s; a 10mA con 0.93Ω habría solo 0.1mW — físicamente imposible disparar). **Chequeo de margen (T7):** I_worst = 3.3/(1.1 + 0.2 + 0.034) ≈ **2.47A** ≥ 1.1A (margen 2.25×); nominal 3.6V → 2.70A; P ignitor ≈ 6.7W por pulso; P MOSFET ≈ 0.21W por pulso (trivial para DPAK). R_wire no medido: estimado 0.2Ω conservador | **Cierra la condición del REPORT.md wave 2: veredicto (a) CONFIRMADO con datos reales** — sin driver, sin cambiar MOSFET. Nota BOM: usar LiPo 1S ≥500mAh (pulso 2.7A trivial para cualquier celda ≥1C). Datos fuente para T7 de executor-4 |
| 2026-09-04 | **Wave 3: T7 integrada + H-2 resuelto** — audit H-2/H-3 ejecutados: restore del `.kicad_pro` (reversión 0.2→0.3 descartada, copia en `/tmp/opencode/kicad_pro.dirty.bak`) y merge `wave3-executor-4` (`faacd71`, T7) con `--no-ff` (`1877ec3`), sin conflictos. Verificación del árbol integrado: ERC 0, DRC 54/61 pre-ruteo con 0 `drill_out_of_range`, T7 grep PASS en main, SPICE exit 0 reproducible, design-notes §6 con I_worst 2.47A. Restante para cerrar la ola: H6 (humano, GUI) → T8 (DRC 0/0) → re-audit | "integra todo" del humano; commit merge 1877ec3 |
| 2026-09-04 | **Auditoría completa (waves 1-3): APPROVED WITH EXCEPTIONS** (`.workflow/audits/wave3.md`). Gates wave 1-2 re-verificados verdes: ERC 0, SPICE reproducible byte-idéntico, T6 se sostiene en HEAD (0 drill_out_of_range, 54/61 pre-ruteo), T7 aritmética reproducida (I_worst 2.47A, margen 2.25×). Hallazgos: H-2 CRÍTICO-acción — working tree tiene reversión sin commitear de T6 (0.2→0.3, las 6 drill_out_of_range vuelven; DRC 60 vs 54 probado); H-3 — T7 (`faacd71`) pusheada pero sin mergear a main; H-1 menor heredado (brief grep comillado). Antes de H6: restore del `.kicad_pro` + merge T7 | Árbol integrado @ 54443c5, auditor sesión fresca |
| 2026-09-15 | **CORRECCIÓN: se revoca la consolidación de radio (H7 → H7b).** La anatomía física del RA-02 (2 filas de 8 agujeros, un borde por cara del módulo de 17×16mm) demuestra que LORA1+LORA2 del esquemático original ya eran el SOCKET del módulo — no dos radios ni variantes TX/RX. El wiring existente casa 1:1 con las filas físicas; solo faltan 3 GND de borde. El planner erró al leer el socket como "módulo partido" — la foto física aportada por el humano fue la evidencia faltante. Lo que sobrevive de la decisión anterior: el rol TX/RX es puro firmware (transceptor half-duplex, un módulo por placa) | Falibilidad registrada: leer netlist sin contexto físico induce a error en hardware. Nada del H7 original llegó a archivo (ni .sch ni .pcb tocaron LORA2); el fix real es mínimo (3 wires) |
| 2026-09-01 | **T6 (wave 3) integrada a main** — merge `wave3-executor-4` (82d910d, merge 75974c5), sin conflictos. DRC en árbol integrado: `drill_out_of_range` = 0 (las 6 del TP4056 desaparecieron); quedan 54 violaciones / 61 unconnected, todas categorías pre-ruteo (H6 pendiente). Nota: el grep literal del brief (`: "0.2"`) no matchea porque KiCad serializa el número sin comillas; semántica verificada en el diff (0.3→0.2, 1 línea) | Board setup corregido ANTES de que el humano abra la GUI, según orden estricto de wave 3 |
| 2026-09-15 | **Protección de batería v1: celda LiPo CON protección integrada (PCM, "protected") + corte por firmware.** El TP4056 es solo cargador (termina a 4.2V; NO protege de sobre-descarga ni de corto en descarga; TEMP→GND = sin NTC). Nivel de celda en display: YA cableado (divisor R5/R6 10k/10k → GPIO26/ADC; 4.2V→2.1V dentro del rango ADC del Pico); el % y las advertencias son de FIRMWARE (ola de software). Regla de firmware: no medir durante el pulso de ignición (el sag de 2.7A corrompe la lectura). NTC al pin TEMP: diferido — solo si V consigue celda con NTC de 3 hilos, se añade el divisor en un fix posterior | La vía con cero cambios de diseño es comprar celda protegida; ponytail: no metemos NTC al PCB que se está por rutear sin la celda concreta en mano |
| 2026-09-15b | **REVISA la fila anterior (2026-09-15, protección de batería): V comprará NTC 10k B3950 pegado a la celda; la celda lleva PCM integrado.** La protección eléctrica vive en el PCM de la celda; el TEMP del TP4056 recupera su función térmica con el NTC externo. H8: pin 1 (TEMP) del ModuloDeCarga1 deja de ir directo a GND → va por `Device:Thermistor_NTC` (Value `NTC 10k B3950`, footprint `PinHeader_1x02_P2.54mm_Vertical`) a GND; ventana térmica ≈ 0–45°C. La regla de firmware "no medir batería durante el pulso de ignición" se mantiene | V confirma la compra del NTC; el fix es 1 símbolo + 1 desconexión en la GUI; el PCB referencia el header 1x02 nuevo cerca de InBatt. BOM +1 |
| 2026-09-16 | **Cierre del periodo wave 1-4**: fab package en `hardware/fab/` (ignition-system-jlcpcb.zip + BOM.csv), waves 1-3 audited, wave 4 exportada. Sesión planificada cerrada con todo pusheado a origin/main (698f603). Pendientes EXTERNOS al repo: pedido JLCPCB, ensamblaje, firmware (src/), security-audit operativo antes del primer disparo | El worktree/rama wave3-executor-4 (tip 709d7ee, ya en main) se elimina al cierre; el humano aprenderá a regenerar el paquete fab él mismo (logo en silkscreen → re-export) |
| 2026-09-16 | **Wave 4 ejecutada para pedido JLCPCB** (humano: "sin burocracia"). Export headless: Gerbers 9 capas (GTL/GBL/GTO/GBO/GTS/GBS/GTP/GM1) + Excellon .drl + job file → `hardware/fab/ignition-system-jlcpcb.zip` (10 files, 117.6K). BOM.csv desde `kicad-cli sch export bom` (28 refs, 27 pieces). Certificación previa al export: ERC 0/0, DRC 0 errores / 0 unconnected pads / 0 drill violations (53 warnings no bloqueantes). Placa 70×50mm ≤100×100 = tier mínimo JLCPCB | Gerbers regenerables con `kicad-cli pcb export gerbers` en cualplesquier momento; única acción restante del proyecto hardware: llenar el formulario de JLCPCB + ensamblar + security-audit operativo antes del primer disparo |
| 2026-09-15c | **H9: switch maestro SW3 en serie con la batería (hecho por V, ERC 0/0).** InBatt+ → SW3 común → VSYS; tercer pin FLOTANTE (nunca GND: un interruptor de potencia a tierra cortocircuita el pack al accionarlo — el 'throw a GND' de SW2 solo aplica a la línea de ignitor, que no tiene fuente detrás). Consecuencia aceptada: cargar requiere switch encendido (TP4056 necesita ver la celda). Con SW3 abierto: consumo 0 (ni el divisor ADC drena). BOM +1 actuator (SPDT) | Placa de cohetería: switch maestro de borde es práctica estándar de aviónica; evita desconectar el JST constantemente (lo que V pidió) |

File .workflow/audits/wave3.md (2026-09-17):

# Audit — Wave 3 (cierre, auditoría 2026-09-16)

**Fecha:** 2026-09-16 · **Auditor:** sesión fresca, `main` @ `709d7ee`
**Alcance:** cierre de la wave 3 post-H7b/H8/H9/H6/T8. Supersede la
supersede de la auditoría de hito (2026-09-04, conservada más abajo).

## Veredicto: APPROVED WITH EXCEPTIONS (ninguna bloquea la ola 4)

## 1. Integridad de integración

- [x] `git status` limpio, sin stashes; `main` == `origin/main`.
- [x] `wave3-executor-4` integrada: `git merge-base --is-ancestor` → MERGED
      (merge `2ae2736`, padres `94f5187`+`00a146f`, sin conflictos).
- [x] Ownership (revisión `git log --stat` de los 12 commits de la ola):
      `.kicad_sch`/`.kicad_pcb` (humano H7b/H8/H9/H6) ✓, `design-notes`/PDF
      (T9) ✓, `.kicad_pro` (709d7ee = restauración T6 0.3→0.2 + GUI save) ✓.
      Excepción 1 (menor): `6004da0` tocó `README.md` + 120 líneas de
      design-notes hechos por el humano directamente en main — territorio
      del executor-4 en el map; contenido correcto y cronológicamente
      antes del PDF. No desvía el gate, registra la Prompt: el humano es
      la autoridad, pero los commits de docs debieron ir al executor.
- [x] Excepción 2 (menor): `94f5187` mezcló cambios GUI del `.kicad_pro`
      (17 l: defaults vacíos de diff_pair/vias, reorder designators — nada
      de reglas) dentro de un `feat:` en vez del `chore(kicad):` separado
      que pide la práctica del audit wave 2. Opcionalmente amender.

## 2. Build & tests (evidencia, árbol integrado 709d7ee)

- [x] ERC: `kicad-cli sch erc` → `Found 0 violations`, exit 0.
- [x] DRC: `kicad-cli pcb drc` → `Found 53 DRC violations`, **0 errores**
      (35 `silk_overlap`, 10 `silk_over_copper`, 8 `lib_footprint_mismatch`
      — todas "Local override; warning"), **`Found 0 unconnected items` /
      `Found 0 unconnected pads`**. Gate "0 errores / 0 unconnected":
      CUMPLE. `drill_out_of_range` = 0 (T6 se sostiene).
- [x] T6 verificada en HEAD: `709d7ee` re-restaura `min_through_hole_diameter`
      0.3→0.2 (reversión de un save anterior de GUI), 1 línea net; diff
      revisado completo, sin claves de reglas alteradas (track_widths +
      Power class 1.0/0.25 = Hito 0 del brief de ruteo).
- [x] Contorno: ≤100×100mm (medido por script sobre el layer Edge.Cuts:
      87.2×42.5mm de bbox) — Hito 0 del brief ✓.
- [x] T7/T9 en design-notes (grep -n): R real 0.8/0.93/1.1Ω, chequeo de
      margen `I_worst = 3.3/(1.1+0.2+0.034) ≈ 2.47A ≥ 1.1A` (margen 2.25×),
      radio "SOCKET del RA-02, 1 radio por placa, rol por firmware", TH1
      NTC B3950, SW3 BATP→VSYS. Cierre de la condición del REPORT wave 2
      re-verificado.
- [x] PDF más nuevo que el último cambio del `.kicad_sch`:
      `94f5187` 13:29 < `00a146f` 14:09 ✓.
- [x] Sin cambios en `sim/wave2/*` ni workflow prohibidos para executor-4
      (`sim/` ausente en todos los --stat) — el gate SPICE de wave 2 no se
      re-corre: nada lo tocó.

## 3. Disciplina ponytail

- [x] H7b: revocación documentada y fix mínimo (3 GND); nada del H7
      original llegó a archivo — verificado en `git log --stat` de la ola.
- [x] Sin deps nuevas; sin abstracciones nuevas (hardware).
- [ ] Menor (hito 4 del brief): 45 warnings silk siguen — el brief dice
      "reduce los que puedas"; 35 `silk_overlap` en una tabla de silks
      aceptable para fab, no es gate. Opcional remarcar en wave 4 si la fab
      corta silks.

## 4. Seguridad

- [x] `git grep -ilE 'api_key|secret|token|password|PRIVATE KEY'` → solo
      `audit-checklist.md` (su propia regex) y `LICENSE-HARDWARE` (texto
      legal). Sin secretos.
- [x] Sin trust boundaries nuevas (ningún input nuevo procesado; hardware
      puro).
- N/A Release gate `skills/security-audit`: ola 4 (plan).

## 5. Handoff

- [x] Este archivo actualiza y supersede el audit del 2026-09-04.
- [ ] plan.md: fila wave 3 del status actualizada por esta auditoría.
- [ ] Ola 4 (Gerbers + BOM + PDF final + security-audit): lista para
      re-planificar; los 53 warnings silk se pueden arrastrar como deuda
      o limpiar antes de exportar (decisión del planner).

---

# (HISTÓRICO) Audit — Wave 3 (auditoría completa, estado 2026-09-04)

**Fecha:** 2026-09-04 · **Auditor:** sesión fresca, árbol integrado en `main` @ `54443c5`
**Alcance:** "audita todo" — re-verificación de los gates de waves 1-2 y estado
completo de la wave 3 (T6 ✓ integrada, H5 ✓, T7 ✓ en rama, H6/T8 pendientes).
Supersede el audit de hito T6 (2026-09-02, conservado en commit `a9d27cc`).

## Veredicto: APPROVED WITH EXCEPTIONS

Todo lo que dice estar hecho lo está, y resiste evidencia: ERC 0, SPICE
reproducible, T6 se sostiene en HEAD, T7 correcto con aritmética verificada.
La wave 3 NO cierra todavía (el gate DRC 0/0 exige H6→T8, pendientes por
orden estricto). Dos excepciones ACCIONABLES listadas abajo; la primera
bloquea abrir KiCad para H6.

## 1. Integridad de integración

- [x] `git status`: **sucio** — `ignition-system.kicad_pro` modificado sin
      commitear. `git stash list` vacío. **Hallazgo H-2 (CRÍTICO-acción):**
      el diff sin commitear REVIERTE T6: `min_through_hole_diameter`
      0.2 → 0.3 (1 hunk, 1 línea). Evidencia DRC abajo: con esta reversión
      las 6 `drill_out_of_range` del TP4056 VUELVEN.
- [x] Ramas: `wave3-executor-4` tip `faacd71` = origin (pusheada). Worktree
      extra único (`dst-ig-wave3-executor-4`), esperado.
- [x] **T7 NO está integrada**: `git log main..wave3-executor-4` →
      `faacd71 docs: anotar medidas reales del ignitor`; en main,
      design-notes.md sigue en `225ae7d` con "confirmar tipo real (~1-2Ω)".
      **Hallazgo H-3 (acción, owner: integrador):** merge `faacd71` → main.
- [x] Ownership map desde el cierre del audit wave 2 (`46f3a95..main`):
      solo `.workflow/*` y el `.kicad_pro` (1 clave, T6) ✓. Commit T7
      `faacd71`: solo `docs/design-notes.md` (§4 BOM + §6, archivos
      concedidos al executor-4) ✓. Sin desviaciones nuevas.
- [x] `.kicad_pcb` sin cambios desde wave 1 (último commit previo
      `36a9e48`) — H6 sin empezar, consistente con el plan.

## 2. Build & tests (evidencia, árbol integrado)

- [x] **ERC** (`kicad-cli sch erc` → `/tmp/opencode/erc-audit-todo.rpt`):
      `Found 0 violations`, exit 0. Gate de wave 1 sigue verde sin regresión.
- [x] **DRC en HEAD (0.2)** — copia de HEAD a /tmp, auditor no toca worktree:
      `** Found 54 DRC violations **`, `drill_out_of_range` = **0** (grep
      cuenta 0), 61 unconnected. Categorías pre-ruteo, igual que el audit T6.
- [x] **DRC en working tree (0.3 revertido)** →
      `/tmp/opencode/drc-audit-worktree.rpt`: `** Found 60 DRC violations **`,
      `drill_out_of_range` = **6**. Prueba de impacto de H-2.
- [x] **T7 verify** (`grep -qiE 'R_max|R_máx|ignitor.*(medid|Ω|ohm)'` contra
      el contenido de la rama): **PASS**.
- [x] **Aritmética de T7 reproducida** (awk):
      `I_worst = 3.3/(1.1+0.2+0.034) = 2.4738 A ≥ 1.1 A` (margen 2.25×);
      nominal 3.6V → 2.6987 A; P_ignitor(nom) 6.77 W ≈ "6.7 W" ✓;
      P_mosfet(I_worst) 0.208 W ≈ "0.21 W" ✓. Números del design-notes y
      decision log correctos. Condición del REPORT.md wave 2 (≤1.1 A)
      CERRADA: veredicto (a) confirmado con datos reales.
- [x] **SPICE reproducible** (`bash sim/wave2/run.sh` en árbol integrado):
      exit 0, `OK: simulacion completa`; `git status` tras la corrida solo
      muestra el `.kicad_pro` preexistente — los `.raw` reproducen
      byte-idéntico (gate wave 2 sigue verde).
- [x] **Wave 2 artifacts**: `sim/wave2/REPORT.md` mantiene veredicto (a) y
      la condición `≤1.1 A` que T7 cierra. `docs/ignition-system.pdf`
      presente (gate wave 1).
- [ ] T8 (DRC final 0 errores / 0 unconnected): no ejecutable — H6 pendiente.
      No es fallo: orden estricto del plan.

## 3. Disciplina ponytail

- [x] Sin deps nuevas; T7 = 1 archivo de docs, +15/−2; T6 = 1 línea.
- [x] Branch isolation respetada: executor-4 pushea solo su rama; T7
      sin mergear (correcto, no se auto-mergeó).
- [x] Sin `ponytail:` nuevos requeridos (docs + 1 línea de regla).
- [~] H-1 (menor, heredado del audit T6, owner: planner): la verify line del
      brief T6 sigue con el grep comillado que nunca matchea
      (`briefs/wave3-executor-4.md:71`). Sin corregir. Semántica ya
      verificada por diff aquí: HEAD tiene el valor 0.2 sin comillas.

## 4. Seguridad

- [x] Scan de secretos (`git grep -iE 'api_key|secret|token|password|PRIVATE KEY'`,
      excluyendo skills/.gitignore/audits): matches solo en
      `audit-checklist.md` (su propia regex) y `LICENSE-HARDWARE` (texto
      legal) — sin secretos reales.
- [x] Sin trust boundaries nuevas (docs + reglas de board).
- N/A Release gate `skills/security-audit`: ola 4 (plan).

## 5. Excepciones y acciones (owners)

> **RESOLUCIÓN 2026-09-04 (mismo día, integrador):** H-2 y H-3 ejecutados y
> verificados. H-2: copia de seguridad del estado sucio en
> `/tmp/opencode/kicad_pro.dirty.bak`, `git restore` del `.kicad_pro` →
> árbol limpio, valor `0.2` (línea 155) verificado. H-3: merge
> `wave3-executor-4` (`faacd71`, T7) → main con `--no-ff` (`1877ec3`), sin
> conflictos. Árbol integrado post-merge: ERC 0, DRC 54/61 pre-ruteo con
> `drill_out_of_range` = 0, T7 grep PASS en main, SPICE exit 0 y
> `git status` limpio tras re-corrida. Queda solo H-1 (planner) y el gate
> DRC 0/0 pendiente de H6→T8.

1. **H-2 (CRÍTICO-acción, owner: humano/integrador, ANTES de H6):** el
   working tree contiene la reversión de T6 sin commitear. Si el humano
   abre la GUI y guarda, la reversión entra al commit del ruteo y las 6
   `drill_out_of_range` vuelven (evidencia: DRC 60 vs 54). Acción: en main,
   `git restore hardware/Kicad/ignition-system/ignition-system.kicad_pro`
   y verificar que vuelve a `0.2`. No commitear la reversión.
2. **H-3 (acción, owner: integrador):** merge `wave3-executor-4` (`faacd71`,
   T7) → main. Sin conflicto esperado: design-notes no cambió en main desde
   `225ae7d`. El gate de wave 3 exige design-notes con los datos reales en
   el árbol integrado; hoy solo están en la rama.
3. **H-1 (menor, owner: planner):** corregir la verify line del brief
   (grep sin comillas) antes de T8. Heredada del audit T6.

## Ruta para cerrar la wave 3

1. Ejecutar H-2 y H-3 (restore del `.kicad_pro` + merge T7).
2. **H6** (humano, GUI): brief `.workflow/briefs/wave3-human-routing.md`
   (net class Power, contorno ~50×70mm, placement por bloques, plano GND en
   B.Cu, ruteo lazo de ignición primero).
3. **T8** (executor-4): `kicad-cli pcb drc` hasta 0 errores / 0 unconnected.
4. Re-auditoría de cierre: gate DRC 0/0 + design-notes integrado →
   veredicto sin excepciones de acción → ola 4 (Gerbers/BOM/PDF +
   `skills/security-audit`).

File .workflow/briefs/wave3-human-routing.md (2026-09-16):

# Brief manual (HUMANO): Wave 3 · H6 — Placement y ruteo en GUI

> Tu tarea en la GUI de KiCad. El executor-4 ya corrigió el board setup
> (min hole 0.2mm). Esta guía va por bloques, en orden. En cada hito puedes
> parar y pedirme verificación con kicad-cli. Regla general: **el cobre de
> abajo (B.Cu) es TODO GND** — ese es tu "GND común" físico: todos los
> retornos vuelven por el plano, sin que tengas que rutear ni un cable de
> tierra.

## Hito 0 — Board setup (10 min)

**Archivo → Configuración de placa → Clases de red (Net Classes):**
1. Añade una clase **`Power`**: `track_width = 1.0 mm`, `clearance = 0.25`,
   `via 0.8/0.4`. Justificación: el lazo del ignitor conmuta ~2.7A de pulso
   (1mm en 1oz ≈ subida de 20°C continuo; el pulso dura ms — sobrado).
2. Asigna a `Power` los nets: **VSYS** y **VBUS**. Todo lo demás se queda en
   Default (0.2mm — suficiente para señales, I2C, SPI y LEDs).
3. Resto de reglas: Default clearance 0.2 ya está bien para JLCPCB
   (mín. fab: pista/gap 0.127, agujero 0.2, borde 0.3).

**Contorno (Edge.Cuts):** el actual (173×110mm) sale del tier caro de la
fab. Redibújalo a **~50×70mm** (rectángulo). Quédate bajo 100×100mm para el
precio mínimo de JLCPCB. La placa cabe: el Pico es 51×17.8mm.

**Agujeros de montaje (decisión mía recomendada: SÍ):** añade 4 footprints
`MountingHole:MountingHole_3.2mm_M3` en las esquinas (3.5mm del borde). Es
una placa de cohete: hay que poder atornillarla al bay de aviónica.

## Hito 1 — Placement por bloques lógicos (30-45 min)

Activa rejilla 0.5mm (abajo a la derecha). Teclas: **M** mover, **R** rotar,
**E** editar. El flujo de señal manda: batería → carga → Pico → radio, y el
lazo de ignición lo más corto posible.

```
┌────────────────────────────────────────────┐
│ SW2      AOD4184A   R7   R11               │   ← bloque IGNICIÓN (lazo corto)
│ [InBatt JST]  [J1 terminal 5mm]            │      J1 en el borde, claro
├────────────────────────────────────────────┤
│ [TP4056] C1  R4  C2   [PICO — centro,      │   ← bloque CARGA a la izq.
│  CHRG STDBY LEDs]      horizontal]         │
├────────────────────────────────────────────┤
│ Display1      [MÓDULO RA-02 — LORA1+LORA2  │   ← socket de DOS headers
│                filas paralela/espejo]      │      separados = módulo real
│ SW1 botón  LEDs estado (borde inferior)    │
└────────────────────────────────────────────┘
```

> **CORRECTO (2026-09-15, H7 revocado): LORA1 y LORA2 son los DOS BORDES
> del MISMO RA-02** (17×16mm, 8 agujeros por borde, pitch 2.54). El módulo
> se sienta sobre los dos headers como un DIP. El rol TX/RX es firmware —
> el cableado es idéntico en ambas placas. H7b: añadir solo los 3 GND
> físicos que faltan (LORA1 pin1, LORA1 pin8, LORA2 pin1).
> **PCB:** los headers deben ir JUNTOS: separación centro-a-centro entre
> LORA1 y LORA2 = la distancia real medida en TU módulo físico (~13-16mm,
> medir con regla), filas paralelas y opuestas, así el módulo cae sobre
> los dos. Soldadura: fila A → GND NSS MOSI MISO SCK DIO5 DIO4 GND;
> fila B → GND GND 3V3 RST DIO0 DIO1 DIO2 DIO3 (DIO1-DIO5 quedan sueltos:
> el firmware usa solo DIO0). Antena IPEX SIEMPRE puesta al transmitir.

Reglas de placement que NO se negocian:
1. **Lazo de ignición compacto:** InBatt/SW2 → J1 → MOSFET drain, en ese
   orden, pegados. Cuanto más corto ese lazo, mejor.
2. **TP4056 pegado a InBatt**, con C1/C2 a <2mm de sus pines (desacoplo).
3. **Desacoplo junto al Pico:** C2 (VBUS) cerca del pin 40 del Pico.
4. **Antenas de LORA1/LORA2 hacia el borde derecho**, y NO pongas cobre ni
   pistas bajo el último tercio de cada módulo (zona de antena).
5. LEDs de estado y SW1 (botón FIRE) en el borde que será accesible.
6. Deja 3mm+ entre cualquier cobre y el Edge.Cuts (regla de fab).

## Hito 2 — Plano GND (10 min)

1. Capa **B.Cu** → Añadir zona rellena (Add Filled Zone) → net **GND** →
   dibuja un rectángulo que cubra TODO el contorno.
2. Añadir zona en **F.Cu** igual (net GND) — la rellenaremos al final, el
   router la respeta igual.
3. **Vías GND**: por cada pad GND de cada chip (Pico ×7, TP4056, MOSFET
   source, C1, C2, LEDs), pon una vía pegada al pad (durante el ruteo: tecla
   **V**; o Place → Via sobre una pista GND). Apunta a ~30-50 vías en total
   al final; al principio basta 1 por pad GND.
4. Después de rutar: Editar → Rellenar todas las zonas.

## Hito 3 — Ruteo en este orden (60-90 min)

Rutea con el router interactivo (**D** sobre un pad; **V** inserta vía;
**Espacio** cambia de capa). Orden estricto:

1. **Lazo de ignición (Power, 1mm):** InBatt+ → (SW2 común/throw) → J1 pin1;
   J1 pin2 → drain del AOD4184A; source → GND con 2 vías al plano. El gate
   (R11→gate, R7→GND) va en 0.2mm — por ahí solo hay µA.
2. **Carga (Power, 1mm):** VBUS del Pico (pin 40) → TP4056 VBUS y CE; BAT+
   del TP4056 → net VSYS (InBatt + Pico pin 39). BAT- y GND: al plano con
   vías.
3. **3V3 y señales (Default, 0.2mm):** I2C al display, SPI a LORA1/2, LEDs,
   botón. Cortas y directas, evitando la zona de antena. A 10MHz no hace
   falta emparejar longitudes — el plano GND debajo hace el trabajo.
4. Si una pista de señal tiene que cruzar otra, usa una vía a B.Cu y otra de
   vuelta — pero B.Cu es del plano GND: los saltos en B.Cu son cortos (2-3
   vías máx por salto) para no cortar el plano.
5. F.Cu GND zone: dibújala al final cubriendo lo que quede libre → rellena
   todas las zonas.

## Hito 4 — Silk y limpieza (15 min)

1. Inspección → DRC: te saldrán warnings de silk (`silk_overlap`,
   `silk_over_copper`). Se arreglan moviendo los textos de referencia fuera
   de los pads (M sobre el texto; E para tamaño/giro). Los que no puedas,
   déjalos: son warnings, no errores — pero reduce los que puedas.
2. Verifica visualmente: contorno cerrado, ningún cobre a <0.3mm del borde,
   antenas libres de cobre.

## Hito 5 — Entrega a verificación

Cuando digas "ruteado": yo lanzo la T8 del executor-4 (DRC headless hasta 0
errores / 0 unconnected) y cerramos la wave 3. Comitea tú el `.kicad_pcb`
en main:

```bash
cd "/home/yovick/repos/Workspace dst-ignition-system/dst-ignition-system"
git add hardware/Kicad/ignition-system/ignition-system.kicad_pcb
git commit -m "feat: ruteo pcb de ignition-system"
git push origin main
```

(Si la GUI toca el `.kicad_pro` al guardar, `chore(kicad):` separado —
práctica ya establecida.)

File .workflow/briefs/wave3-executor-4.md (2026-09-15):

# Brief: Wave 3 · Executor 4

> Preparas el PCB para que el humano rutee: corriges board setup, incorporas
> los datos reales del ignitor cuando el humano los mida, y verificas DRC
> hasta 0. El ruteo en sí NO es tuyo: lo hace el humano en la GUI.

## Task

Tres tareas SECUENCIALES (una commit por tarea):

- **T6 (hazla primero, ANTES de que el humano abra KiCad):** en
  `hardware/Kicad/ignition-system/ignition-system.kicad_pro`, cambia la clave
  `"min_through_hole_diameter"` de `"0.3"` a `"0.2"` (bloque
  `design_settings.rules`, ~línea 155). NO toques ninguna otra clave. Luego
  corre DRC y verifica que las 6 violaciones `drill_out_of_range` del TP4056
  desaparecen (el resto de violaciones silk/unconnected siguen, es un board
  sin rutear — normal).
- **T7 (cuando el humano te pase los datos del ignitor):** actualiza
  `docs/design-notes.md` §6 (pendiente "Ignitor/e-match") y §4 (BOM) con los
  números reales: R_min/R_typ/R_max (medidos), R_wire del cableado, y si el
  humano hizo la prueba destructiva, I_fire medido. Haz el chequeo de margen:
  `I_worst = 3.3 / (R_max + R_wire + 0.034)`. Debe ser ≥ 1.1 A (condición de
  `sim/wave2/REPORT.md`). **Si da < 1.1 A: PARA y reporta al planner — no
  decidas tú cambiar MOSFET ni driver.** Si da OK, anota el resultado con la
  fórmula y los números en design-notes.
- **T9 (tras el fix H7 del humano, ANTES de que siga el ruteo):** el humano
  consolidó la radio en un header: borró LORA2-Sx1278 y reconectó RST/DIO0/
  3V3/GND a LORA1-Sx1278 (ver decision log 2026-09-15). Verifica ERC 0/0,
  regenera `docs/ignition-system.pdf` con kicad-cli y actualiza
  `docs/design-notes.md`: §2 (pin map — RST/DIO0 ahora en LORA1, borra la
  nota de LORA2), §4 (BOM — fuera el conector de LORA2), §6 (nota radio →
  "UN SX1278 RA-02 por placa; rol TX/RX por firmware; transceptor half-duplex").

- **T8 (cuando el humano termine el ruteo):** corre `kicad-cli pcb drc`,
  reporta el resultado al planner. Si hay errores: reporta el .rpt COMPLETO
  (tú no ruteas, no edites el .kicad_pcb). Itera solo cuando el humano diga
  que ya arregló algo.

## Definition of done

- T6: la clave cambiada, DRC sin `drill_out_of_range`, y la verify command pasa.
- T7: design-notes tiene los valores reales y el chequeo de margen con fórmula
  y números; o el bloqueo reportado al planner.
- T8: el DRC final del árbol integrado da 0 errores / 0 unconnected (o el
  reporte de lo que falte, sin editarlo tú).
- La verify command de la tarea activa pasa antes de cada commit.

## Files you own

- `hardware/Kicad/ignition-system/ignition-system.kicad_pro` (SOLO T6, SOLO
  la clave min_through_hole_diameter) — T6 ya integrada
- `docs/design-notes.md` (§4, §6 en T7; §2, §4, §6 en T9)
- `docs/ignition-system.pdf` (SOLO T9: regeneración con kicad-cli)

## Files forbidden

- `hardware/Kicad/ignition-system/ignition-system.kicad_sch` (congelado en
  wave 3; si crees que necesita un cambio, reporta al planner)
- `hardware/Kicad/ignition-system/ignition-system.kicad_pcb` (del humano en
  GUI; tú solo lo LEES con kicad-cli)
- `sim/wave2/*`, `.workflow/*`, `README.md`, `src/*`

## Read first

- `.workflow/plan.md` — sección Wave 3 (orden estricto) + decision log.
- `sim/wave2/REPORT.md` — la condición "ignitor ≤ 1.1 A" y el Rds_eff≈34mΩ
  que usa el chequeo de margen.
- `docs/design-notes.md` — §5 estado del PCB (las 6 drill_out_of_range) y
  §6 (pendiente ignitor) — es lo que T6/T7 cierran.
- `.workflow/audits/wave2.md` — excepción 1: si la GUI reordena el
  `.kicad_pro`, eso se commitea como `chore(kicad):` separado.

## Verify command

```bash
# T6 — la corrección de reglas es real:
kicad-cli pcb drc --output /tmp/opencode/drc-t6.rpt \
  hardware/Kicad/ignition-system/ignition-system.kicad_pcb \
  && ! grep -q drill_out_of_range /tmp/opencode/drc-t6.rpt \
  && grep -q '"min_through_hole_diameter": "0.2"' \
     hardware/Kicad/ignition-system/ignition-system.kicad_pro

# T7 — los datos reales y el chequeo están en design-notes:
grep -qiE 'R_max|R_máx|ignitor.*(medid|Ω|ohm)' docs/design-notes.md

# T8 — DRC final limpio:
kicad-cli pcb drc --output /tmp/opencode/drc-final.rpt \
  hardware/Kicad/ignition-system/ignition-system.kicad_pcb \
  && ! grep -qE '\bErrors? [1-9]' /tmp/opencode/drc-final.rpt
```

La ruta del repo tiene ESPACIOS: cita siempre las rutas entre comillas.

## Commit

- MANDATORY: conventional commits, resumen corto, imperativo, una línea.
  Ejemplos: `build: bajar min hole a 0.2mm`, `docs: anotar medidas reales
  del ignitor`. Under ~72 chars. No AI attribution, no trailers.
- One logical change per commit. One commit per task (T6, T7, T8 son commits
  separados).
- Commit ONLY tus archivos.
- BRANCH ISOLATION (mandatory): commit y push SOLO a tu rama de worktree
  `wave3-executor-4` — `git push origin wave3-executor-4` tras cada commit.
  Nunca a `main` ni a otra rama; nunca merge/rebase/fast-forward de ramas
  ajenas.
- No hagas `cd` fuera de tu worktree ni `git checkout|switch|branch|worktree|stash`.

## Report back

- T6: salida del DRC (número de violaciones antes/después).
- T7: los números del ignitor y el resultado del chequeo de margen (o el
  bloqueo si < 1.1A).
- T8: el DRC final con conteo exacto de errores/warnings/unconnected, y el
  listado de violaciones si las hay.
- Cualquier desviación del ownership map: reportada, nunca "arreglada".

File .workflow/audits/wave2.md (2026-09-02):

# Audit — Wave 2 (Validación SPICE del disparo)

**Fecha:** 2026-09-01 · **Auditor:** sesión fresca, árbol integrado en `main` @ `46f3a95`
**Alcance:** ola 2 (`wave2-executor-3` + fix humano H4) según `.workflow/plan.md`

## Veredicto: APPROVED WITH EXCEPTIONS

La ola cumple su gate: el informe SPICE existe, corre en ngspice-45 y es
reproducible; el veredicto (a) "OK para rutear con AOD4184A" está soportado
por números que reproduje yo mismo. Dos excepciones menores listadas abajo,
ambas de bajo riesgo y ya mitigadas. La ola 3 (ruteo) puede arrancar, con la
condición del informe: **medir el ignitor real al recibirlo (≤1.1 A)**.

## 1. Integridad de integración

- [x] Worktrees fusionados: `wave2-executor-3` (tip `2c1a827`) fusionada en
      `main` vía `9c72979`. `git log --graph` lo confirma; `git branch -a`
      no muestra ramas sin fusionar.
- [x] `git status` limpio; `git stash list` vacío.
- [x] Diff vs plan (ownership map):
  - `2c1a827` (executor-3): solo `sim/wave2/*` (9 archivos, +8180) ✓
  - `d453565` (H4 humano): solo `ignition-system.kicad_sch` ✓
  - `a9de791` (humano): `ignition-system.kicad_pro` — **EXCEPCIÓN 1** (ver abajo)
  - `46f3a95`, `f86ebb4`, `ce80c91`: solo `.workflow/plan.md` ✓

## 2. Build & tests (evidencia)

- [x] **ERC en árbol integrado** (H4 + renombres de designators verificados):
  ```
  kicad-cli sch erc --output /tmp/opencode/erc-wave2-audit.rpt hardware/Kicad/ignition-system/ignition-system.kicad_sch
  → exit 0 · **ERC messages: 0  Errors 0  Warnings 0**
  ```
- [x] **Verify #1 del brief:** `bash sim/wave2/run.sh` → exit 0, `CASE4`
  alcanzado, salidas regeneradas en `sim/wave2/out/`. Re-corrida deja
  `git status` limpio: los `.raw` comprometidos **reproducen byte-idéntico**.
- [x] **Verify #2 del brief:** `grep -qiE 'veredicto|recomendaci|conduce|0\.[0-9]+ ?A' REPORT.md` → PASS.
- [x] **Cross-check auditor vs REPORT.md** (re-simulé yo mismo, ngspice-45):

  | Caso | REPORT | Medido por auditor |
  |------|--------|--------------------|
  | 1 (1.5Ω/3.6V) | 2.347 A · Vds 79.5 mV | `id_final=2.346969`, `vds_final=7.9547e-2` ✓ |
  | 2a (2Ω/3.6V) | 1.770 A · 59.5 mV | `1.770268` · `5.9464e-2` ✓ |
  | 2b (1Ω/3.6V) | 3.480 A · 120.2 mV | `3.479834` · `1.2017e-1` ✓ |
  | 2c (2Ω/3.3V peor) | 1.623 A · 54.4 mV | `1.622806` · `5.4389e-2` ✓ |
  | 3 (Id=1A) | VGPIO≈2.80V, gate≈2.74V | `vgs_at_1a=2.7975` → gate 2.737 ✓ |
  | 4 (slew) | t90=2.78 µs | `t90_id=102.7792µs` − 100µs = 2.78µs ✓ |

- [x] Aritmética del informe verificada: Rds_eff = 79.5mV/2.347A = 33.9 mΩ ✓;
      P = Id²·Rds = 0.187 W (informe: 0.19 W) ✓.
- [x] Modelo inline en `ignition-sim.cir` **idéntico** a
      `Local Spice/AOD4184A.lib` (diff de parámetros: ninguno).
- [x] Topología simulada = esquemático real: netlist de KiCad confirma
      `R11 IGNITION_GATE <gate> 220`, `R7 <gate> GND 10k`, AOD4184A1 presente,
      `.include` apunta al `.lib` local.

## 3. Disciplina ponytail

- [x] Sin dependencias nuevas: ngspice ya instalado (gate de la ola), bash.
- [x] `run.sh` = 18 líneas; `.cir` autocontenido (modelo inline, no includes
      externos); 4 casos con `alterparam`+`reset`, sin duplicar netlists.
- [x] `run.sh` deja un check ejecutable mínimo (`grep -q CASE4`) — cumple la
      regla de "un check que falla si la lógica se rompe".
- [ ] OBSERVACIÓN: los `.raw` de `out/` (~8k líneas) son artefactos
      regenerables comprometidos en git. Defendible como evidencia adjunta
      del audit gate ("salida transitoria/dc adjunta"), pero si vuelve a
      doler en diffs, `sim/wave2/out/` a `.gitignore` y el gate se demuestra
      con un run. No bloquea.
- Trivial: typo "tedea" en REPORT.md:99 (por "tee-a"). No bloquea.

## 4. Seguridad

- [x] Scan de secretos (`git grep -iE '(api[_-]?key|secret|token|password|...)'`):
      solo matches en docs de `skills/` y `.gitignore` — **sin secretos reales**.
- [x] `.gitignore` cubre `*.log`, `*.secret`, `secrets/`, `.history/`.
- [x] `run.sh` sin `eval`, sin entradas de confianza; no hay trust boundaries
      nuevas en esta ola.
- N/A Release gate `skills/security-audit`: corresponde a la ola 4 (plan),
  no a esta ola.

## 5. Excepciones

1. **`a9de791` toca `ignition-system.kicad_pro` fuera del ownership map de la
   ola 2** (el mapa solo concedía el `.kicad_sch` para H4; el `.kicad_pro` es
   material de la ola 3). Riesgo ~cero: 1 línea mecánica (`used_designators`
   reordenado, side-effect de guardar la GUI de KiCad), commit del humano.
   Owner: humano. Mitigado: el cambio no afecta diseño ni DRC futuro. Regla
   para ola 3: si la GUI reordena el `.kicad_pro` al guardar, commitearlo
   como `chore(kicad):` separado y documentarlo — ya es la práctica observada.
2. **La ola 1 nunca tuvo archivo de auditoría** en `.workflow/audits/` (la
   carpeta no existía; quedó "integrated" sin registro formal). Mitigado en
   esta auditoría re-verification: ERC 0/0 hoy, sin net huérfano `VCC`
   (`grep -i vcc` en netlist → sin matches), PDF regenerado existe
   (`0b2d5ee`), `docs/design-notes.md` presente. Owner: planner — para la
   ola 3+, cerrar cada ola con su archivo de auditoría.

## Conclusión y ruta a la ola 3

El gate de la ola 2 queda **VERDE con la condición ya documentada en el
informe**: al recibir el ignitor/e-match real, medir su corriente; si >1.1 A,
escalar a (b) driver de gate o (c) MOSFET con Vto<2V antes de rutear la zona
de potencia. La ola 3 (ruteo en GUI + `kicad-cli pcb drc`) puede planificarse.

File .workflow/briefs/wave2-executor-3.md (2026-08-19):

# Brief: Wave 2 · Executor 3

> Valida por SPICE si el AOD4184A conduce el ignitor con gate a 3.3V — ANTES
> de que el humano rutee. Tú no tocas archivos KiCad: creas un subcircuito de
> simulación aparte.

## Task

Simular el circuito de ignición con ngspice y entregar un informe con
veredicto. NO se simula la placa completa ni el RP2040: un GPIO digital es
una fuente pulsada 0→3.3V.

**Subcircuito a simular** (spoilers del esquemático):

```
V1 (fuente pulsada 0→3.3V, simula el GPIO15/IGNITION_GATE)
 ├─ R11 220Ω
 │    └─ nodo GATE ── R7 10kΩ ── GND
 │                   │
 │            AOD4184A (modelo: Local Spice/AOD4184A.lib)
 │             G=GATE  D=J1.2  S=GND
 │                            │
 VSYS (fuente DC 3.6V, LiPo nominal) ── J1 (ignitor, R=1.5Ω) ── D
```

**Casos de test** (todos con `.tran` y/o `.dc`):
1. Vgs=3.3V, ignitor 1.5Ω, VSYS=3.6V → ¿corriente de disparo? ¿Vds?
2. Vgs=3.3V, ignitor 2Ω y 1Ω (márgenes) → rango de corriente.
3. Barrido `.dc v1 0 3.3 0.1` → curva Id vs Vgs con carga fija.
4. Slew rate del gate con R11=220Ω + Cgs del modelo → tiempo hasta que la
   corriente alcanza el 90%.

**Entregables** (todos nuevos, en `sim/wave2/`):
- `ignition-sim.cir` — netlist ngspice completo con los 4 casos comentados.
- `run.sh` — corre ngspice y guarda salidas en `sim/wave2/out/`.
- `REPORT.md` — veredicto: ¿el AOD4184A conduce ≥ criterio (≥0.5A de margen
  sobre lo que pida el ignitor real)? Tabla con resultados por caso,
  potencia disipada en el MOSFET (P = Id²·Rds), y recomendación:
  (a) OK para rutear con este MOSFET; (b) añadir driver de gate;
  (c) cambiar a MOSFET con Vto<2V.

Si `kicad-cli sch export netlist --format spice` genera el netlist del
subcircuito completo, puedes usarlo como base, pero el .cir entregado debe
ser autocontenido y correr solo (no depende de abrir KiCad).

## Definition of done

- `sim/wave2/ignition-sim.cir`, `run.sh` y `REPORT.md` existen.
- `run.sh` corre `ngspice` sin errores y produce salidas en `sim/wave2/out/`.
- `REPORT.md` tiene veredicto CON números (Id, Vds, potencia) y uno de los 3
  veredictos (a/b/c) razonados.
- La verify command pasa.

## Files you own

- `sim/wave2/` (todo lo que crees ahí)

## Files forbidden

- `hardware/Kicad/ignition-system/*` (todo — salvo LEER
  `Local Spice/AOD4184A.lib` y el `.kicad_sch` para sacar valores)
- `docs/*`, `README.md`, `.gitignore`, `.workflow/*`, `.history/`
- `src/*`

## Read first

- `hardware/Kicad/ignition-system/Local Spice/AOD4184A.lib` — el modelo
  VDMOS (Kp, Vto=2.61, Rd, Rg, Cgs=1365p, tt=42n).
- `hardware/Kicad/ignition-system/ignition-system.kicad_sch` — valores de
  R7/R11 y la topología del disparo (≈líneas 8876-8940 para AOD4184A1,
  8307-8380 para R11, 9674-9750 para R7).
- `.workflow/plan.md` — Wave 2 y decision log.

## Verify command

```bash
# 1. El netlist corre en ngspice:
bash sim/wave2/run.sh && ls sim/wave2/out/ | grep -q '\.raw\|\.log' 
# 2. El informe tiene veredicto y números:
grep -qiE 'veredicto|recomendaci|conduce|0\.[0-9]+ ?A' sim/wave2/REPORT.md
```

Instala ngspice si falta: `nix profile install nixpkgs#ngspice` (o el
equivalente en tu distro). Si no hay forma de instalarlo, reporta el bloqueo
en vez de inventarte resultados.

## Commit

- Conventional commits, una línea, imperativo. Ejemplos:
  `feat: add spice ignition simulation`,
  `docs: add spice verification report`.
- BRANCH ISOLATION: commit AND push ONLY a `wave2-executor-3`.
- Nunca `cd` fuera de tu worktree ni `git checkout|switch|branch|worktree|stash`.

## Report back

- Veredicto (a/b/c) y los números clave.
- Dificultades con el modelo AOD4184A (VDMOS de Bordodynov) o con ngspice.
- Recomendación concreta para el humano (qué cambiaría si el veredicto no es OK).

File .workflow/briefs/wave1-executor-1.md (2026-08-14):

# Brief: Wave 1 · Executor 1

> El humano hace los fixes del esquemático en GUI (`wave1-human-schematic.md`).
> TÚ no editas KiCad: verificas el resultado con kicad-cli y regeneras el PDF.

## Task

1. **Verificar el esquemático tras el fix del humano** (headless, sin abrir
   GUI): el ERC debe reportar 0 errores y el netlist debe reflejar los 3
   cambios acordados.
2. **Regenerar `docs/ignition-system.pdf`** — el PDF actual data del commit
   `0df3d5b` (2026-08-08) y está desactualizado respecto al esquemático
   corregido. Usa `kicad-cli sch export pdf`.

Si la verificación falla: NO arregles el `.kicad_sch` por texto tú mismo
(territorio del humano en GUI). Reporta el fallo con la salida exacta del
ERC y para.

## Definition of done

- ERC: 0 errores (warnings documentados si quedan).
- Netlist: `ModuloDeCarga1.8` (CE) está en el net `VBUS`; `ModuloDeCarga1.1`
  (TEMP) está en el net `GND`; no existe net "VCC" huérfano.
- `docs/ignition-system.pdf` regenerado y más nuevo que el commit `0df3d5b`.
- La verify command pasa.

## Files you own

- `docs/ignition-system.pdf` (regenerado)

## Files forbidden

- `hardware/Kicad/ignition-system/ignition-system.kicad_sch` (si lo editas,
  corres el riesgo de pisar al humano; si el ERC falla, reporta, no arregles)
- `hardware/Kicad/ignition-system/ignition-system.kicad_pcb`
- `hardware/Kicad/ignition-system/ignition-system.kicad_pro`
- `hardware/Kicad/ignition-system/DRC.rpt`, `Local Spice/*`, `.history/`, `*.lck`
- `docs/design-notes.md`, `README.md`, `.gitignore`, `.workflow/*` (salvo leer)

## Read first

- `.workflow/plan.md` → Decision log y plan de integración.
- `.workflow/briefs/wave1-human-schematic.md` → qué se supone que cambió.

## Verify command

```bash
# 1. ERC 0 errores:
kicad-cli sch erc --output /tmp/opencode/erc-e1.rpt \
  hardware/Kicad/ignition-system/ignition-system.kicad_sch
grep -E "Errors [0-9]+" /tmp/opencode/erc-e1.rpt       # esperado: Errors 0

# 2. Netlist: VBUS incluye ModuloDeCarga1.8, GND incluye ModuloDeCarga1.1,
#    y el net VCC huérfano no existe:
kicad-cli sch export netlist --format kicadsexpr --output /tmp/opencode/net-e1.net \
  hardware/Kicad/ignition-system/ignition-system.kicad_sch
node -e '
const fs=require("fs");const t=fs.readFileSync("/tmp/opencode/net-e1.net","utf8");
const b=t.split("\t(nets\n")[1].split("\n\t)\n)")[0];
for(const bl of b.split("\t\t(net\n")){
  const n=bl.match(/\(name "([^"]*)"\)/);if(!n)continue;
  const c=[...bl.matchAll(/\(ref "([^"]+)"\)\n\t\t\t\t\(pin "(\d+)"\)/g)];
  console.log(n[1].padEnd(30), c.map(x=>x[1]+"."+x[2]).join(","));
}'
# Esperado: VBUS incluye ModuloDeCarga1.8; GND incluye ModuloDeCarga1.1;
#           sin línea "VCC".

# 3. PDF regenerado (más nuevo que el del 8-ago):
kicad-cli sch export pdf --output docs/ignition-system.pdf \
  hardware/Kicad/ignition-system/ignition-system.kicad_sch
ls -la docs/ignition-system.pdf
```

Ejecuta 1 y 2 ANTES de tocar nada. Si pasan, ejecuta 3 y commitea el PDF.
Si fallan, reporta sin commitear nada.

## Commit

- Conventional commit: `docs: regenerate schematic pdf after erc fixes`
  (una línea, imperativo, <72 chars). Commit ONLY tu archivo.
- BRANCH ISOLATION: commit AND push ONLY a `wave1-executor-1`.
- Nunca `cd` fuera de tu worktree ni `git checkout|switch|branch|worktree|stash`.

## Report back

- Salida de los 3 checks (o el fallo exacto).
- Warnings del ERC que quedaron (si alguno).

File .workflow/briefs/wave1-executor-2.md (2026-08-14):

# Brief: Wave 1 · Executor 2

> Documentación y repo hygiene — texto puro. No tocas NINGÚN archivo KiCad.
> Puedes correr en paralelo con el trabajo del humano y del executor-1.

## Task

1. **Crear `docs/design-notes.md`** — la referencia de diseño del sistema.
   Contenido mínimo (todo en español, como el repo):
   - **Topología**: RP2040 (Pico) + TP4056 (carga Li-ion) + AOD4184A (NMOS
     de ignición) + 2 conectores LoRa/nRF24 + display I2C + LEDs. Mapa de
     bloques en ASCII.
   - **Mapa de pines RP2040** (fuente: netlist exportado — ver read-first):
     GPIO13=BTN_FIRE, GPIO15=IGNITION_GATE, GPIO10/11/12=LED_LINK/MODO/
     ARMADO, GPIO26/ADC0=ADC_Bateria, GPIO4/5=I2C display, GPIO16-22=SPI
     LORA, VBUS/VSYS/3V3/GND.
   - **Decisiones de diseño** (del decision log en `.workflow/plan.md`):
     CE→VBUS, TEMP→GND (con `ponytail:` naming el techo y upgrade path),
     labels DIO eliminados, human-in-the-loop como modelo de trabajo.
   - **BOM preliminar**: componentes, valores, footprints (extraerlos del
     `.kicad_sch` — puedes LEERLO, nunca escribirlo).
   - **Estado del PCB**: no ruteado (0 pistas/vias), DRC 34 violaciones
     (6 drill 0.2mm < 0.3mm min + 28 silk) y 59 pads sin conectar —
     pendiente ola 3.
   - **Pendientes/riesgos**: margen Vto del AOD4184A vs 3.3V (ola 2),
     firmware `src/` aún vacío, confirmar tipo de ignitor y módulos.
2. **Añadir `*.lck` a `.gitignore`** — los `~*.kicad_sch/pcb/pro.lck` son
   locks de KiCad abierto y ensucian `git status`.
3. **Actualizar `README.md`** — el README promete firmware Rust/Embassy que
   aún no existe en `src/` (vacío). Añade sección "Estado del hardware"
   apuntando a `docs/design-notes.md` y a los artefactos. No inventes
   features ni inventes un estado que no sea cierto.

## Definition of done

- `docs/design-notes.md` existe y cubre los 6 bloques del task.
- `.gitignore` ignora `*.lck` y `git status` queda limpio de `.lck`.
- `README.md` refleja el estado real (sin prometer firmware inexistente).
- La verify command pasa.

## Files you own

- `docs/design-notes.md` (nuevo)
- `.gitignore`
- `README.md`

## Files forbidden

- `hardware/Kicad/ignition-system/*` (todo el árbol KiCad — LEER sí,
  ESCRIBIR nunca; ni siquiera el PDF, ese es del executor-1)
- `docs/ignition-system.pdf` (executor-1)
- `docs/.gitkeep`
- `.workflow/*`, `AGENTS.md`, `src/*`

## Read first

- `.workflow/plan.md` — decision log con las decisiones ya tomadas.
- `hardware/Kicad/ignition-system/ignition-system.kicad_sch` — instancias
  de componentes (Reference/Value/Footprint) ≈líneas 6300-9800.
- `hardware/Kicad/ignition-system/DRC.rpt` — estado del PCB.
- `README.md` actual.

Para el mapa de pines usa el netlist exportado:

```bash
kicad-cli sch export netlist --format kicadsexpr --output /tmp/opencode/net-e2.net \
  hardware/Kicad/ignition-system/ignition-system.kicad_sch
```

## Verify command

```bash
# 1. design-notes existe y no está vacío:
test -s docs/design-notes.md

# 2. .gitignore cubre los .lck:
grep -q 'lck' .gitignore

# 3. README actualizado menciona el estado del hardware:
grep -q 'design-notes' README.md

# 4. git status limpio de .lck:
git status --short | grep -c 'lck' ; echo "esperado: 0"
```

Ejecuta las 4 antes de commitear.

## Commit

- Conventional commits, una línea, imperativo. Ejemplos:
  `docs: add design notes for ignition system`,
  `chore: ignore kicad lock files`,
  `docs: update readme hardware status`.
  Tres cambios lógicos → tres commits.
- Commit ONLY your owned files.
- BRANCH ISOLATION: commit AND push ONLY a `wave1-executor-2`.
- Nunca `cd` fuera de tu worktree ni `git checkout|switch|branch|worktree|stash`.

## Report back

- Archivos creados/modificados y resumen.
- Salida de la verify command (4 checks).
- Discrepancias encontradas entre netlist/DRC y lo documentado.

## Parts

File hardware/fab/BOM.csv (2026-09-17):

Refs | Value | Footprint | Qty | DNP
AOD4184A1 | NMOS | Package_TO_SOT_SMD:TO-252-2 | 1
BLED1 | LED | LED_SMD:LED_0805_2012Metric | 1
C1 | 10uf | Capacitor_SMD:C_0805_2012Metric | 1
C2 | 10uf | Capacitor_SMD:C_0805_2012Metric | 1
CHRG1 | LED | LED_SMD:LED_0805_2012Metric | 1
Display1-SSD1306 | Conn_01x04 | Connector_PinHeader_2.54mm:PinHeader_1x04_P2.54mm_Vertical | 1
IGNITOR1 | Screw_Terminal_01x02 | TerminalBlock:TerminalBlock_MaiXu_MX126-5.0-02P_1x02_P5.00mm | 1
InBatt1 | Conn_01x02 | Connector_JST:JST_PH_S2B-PH-K_1x02_P2.00mm_Horizontal | 1
LORA-Sx1278(A)1 | Conn_01x08 | Connector_PinHeader_2.54mm:PinHeader_1x08_P2.54mm_Vertical | 1
LORA-Sx1278(B)1 | Conn_01x08 | Connector_PinHeader_2.54mm:PinHeader_1x08_P2.54mm_Vertical | 1
ModuloDeCarga1 | TP4056-42-ESOP8 | Package_SO:SOIC-8-1EP_3.9x4.9mm_P1.27mm_EP2.41x3.3mm_ThermalVias | 1
R1 | 330 | Resistor_SMD:R_0805_2012Metric | 1
R2 | 330 | Resistor_SMD:R_0805_2012Metric | 1
R3 | 330 | Resistor_SMD:R_0805_2012Metric | 1
R4 | 2.2k | Resistor_SMD:R_0805_2012Metric | 1
R5 | 10k | Resistor_SMD:R_0805_2012Metric | 1
R6 | 10k | Resistor_SMD:R_0805_2012Metric | 1
R7 | 10k | Resistor_SMD:R_0805_2012Metric | 1
R8 | 1k | Resistor_SMD:R_0805_2012Metric | 1
R9 | 1k | Resistor_SMD:R_0805_2012Metric | 1
R11 | 220 | Resistor_SMD:R_0805_2012Metric | 1
RaspberryPi_Pico1-RP2040 | RaspberryPi_Pico | Module:RaspberryPi_Pico_Common_Unspecified | 1
RLED1 | LED | LED_SMD:LED_0805_2012Metric | 1
STDBY1 | LED | LED_SMD:LED_0805_2012Metric | 1
SW1 | SW_Push | Connector_JST:JST_PH_S2B-PH-K_1x02_P2.00mm_Horizontal | 1
SW2 | SW_SPDT | Button_Switch_THT:SW_E-Switch_EG1224_SPDT_Angled | 1
SW3 | SW_SPDT | Button_Switch_THT:SW_E-Switch_EG1224_SPDT_Angled | 1
TH1 | NTC 10k B3950 | Connector_JST:JST_PH_S2B-PH-K_1x02_P2.00mm_Horizontal | 1
YLED1 | LED | LED_SMD:LED_0805_2012Metric | 1

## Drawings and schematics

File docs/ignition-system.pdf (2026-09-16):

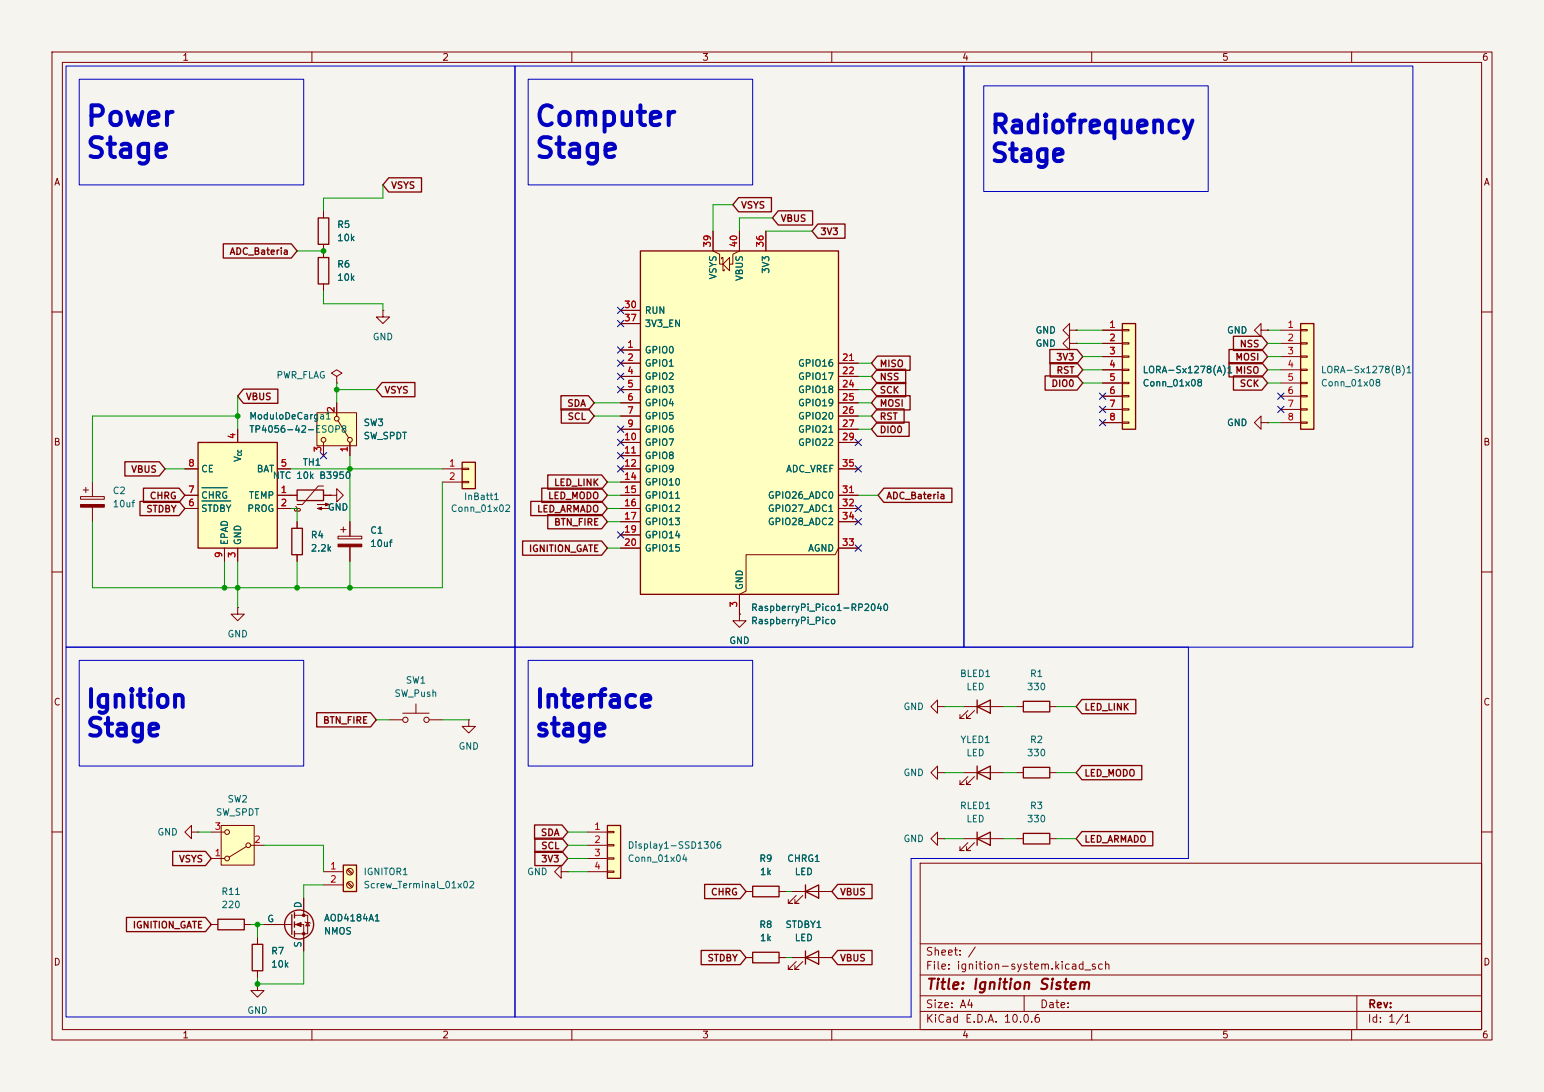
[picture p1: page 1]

Size: A4 | Rev:
KiCad E.D.A. 10.0.6 | Id: 1/1

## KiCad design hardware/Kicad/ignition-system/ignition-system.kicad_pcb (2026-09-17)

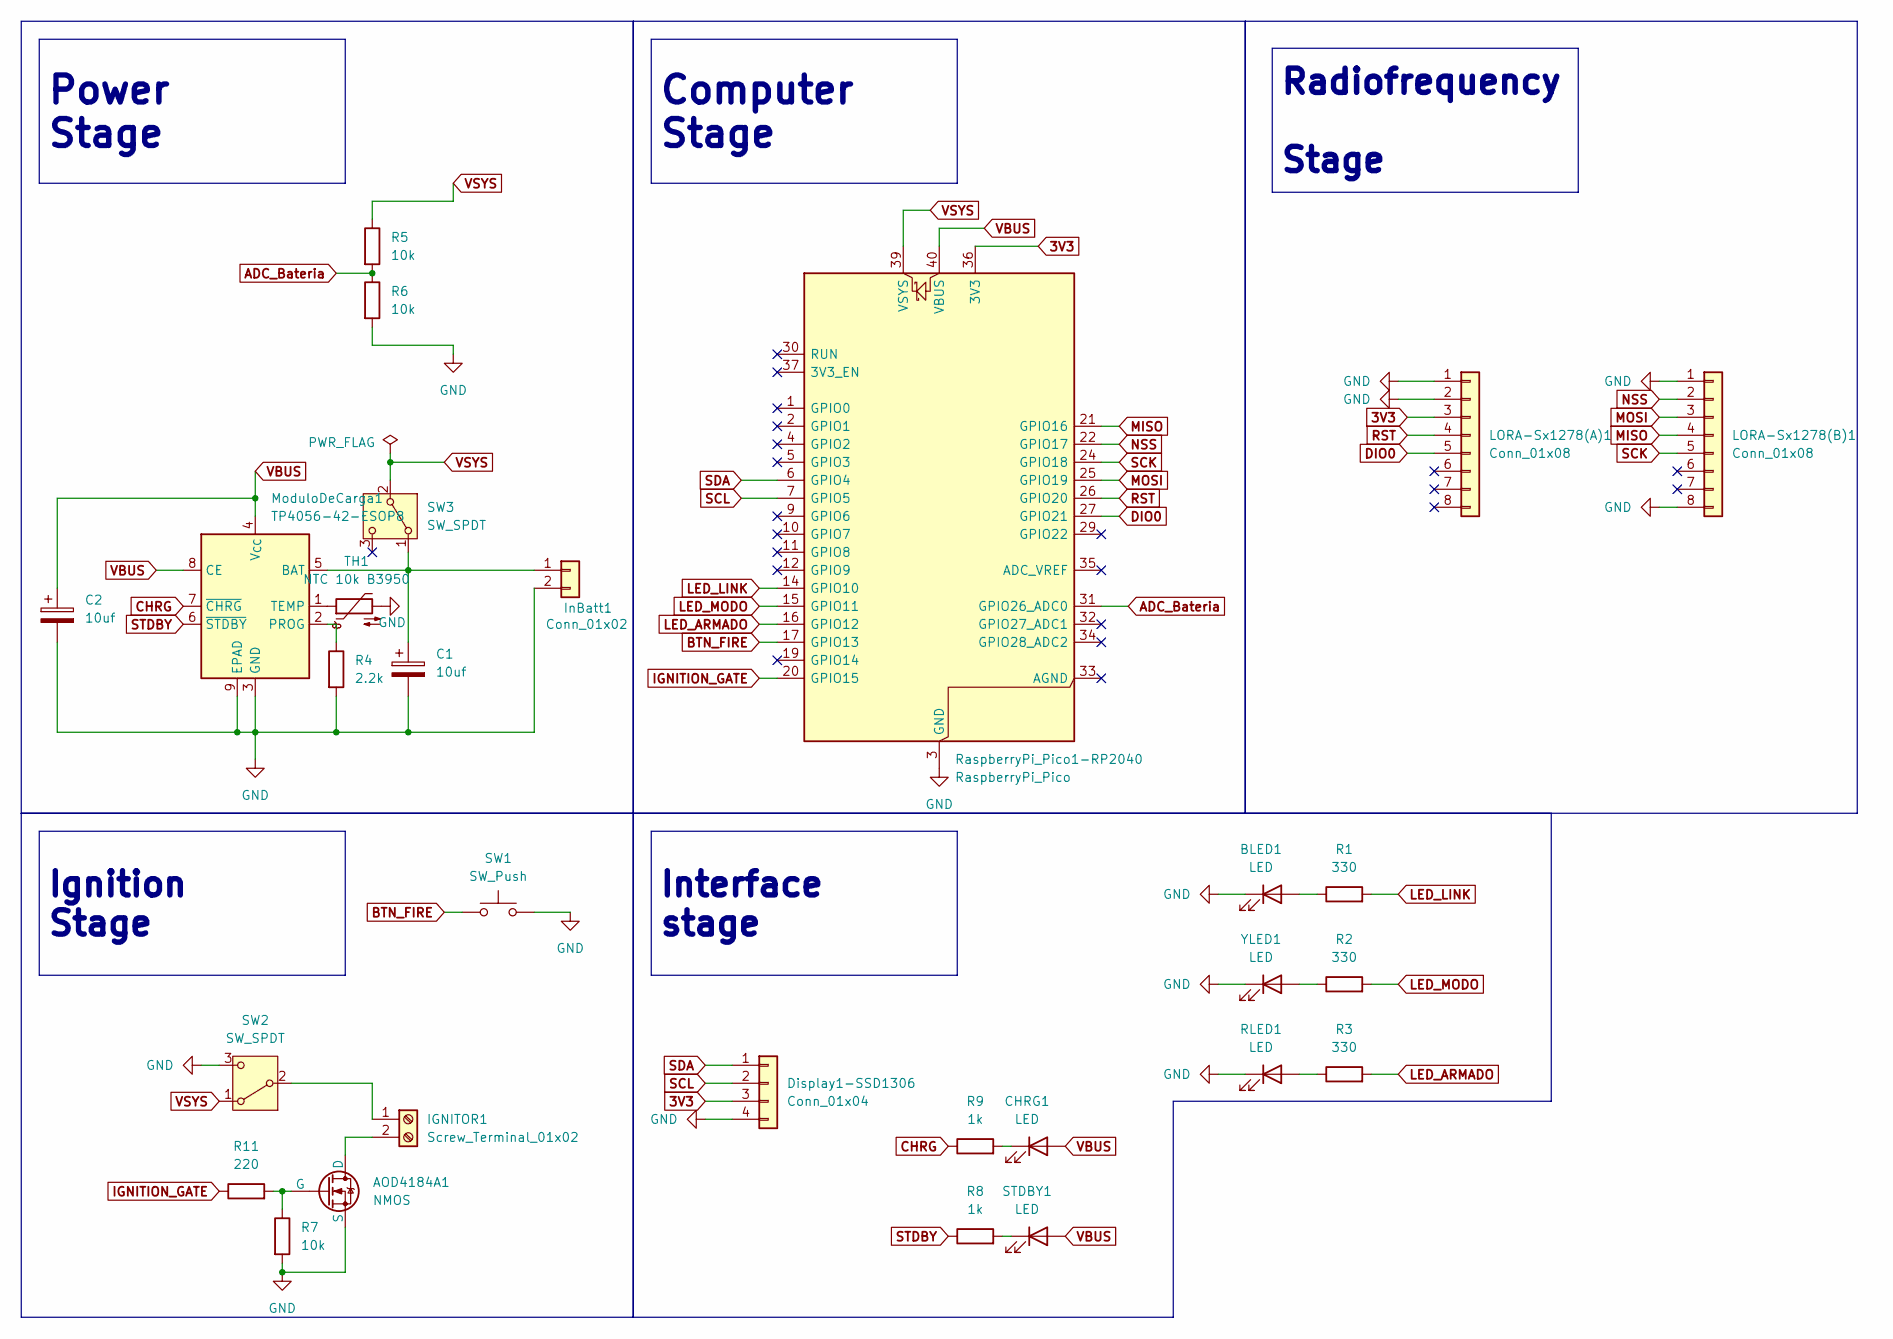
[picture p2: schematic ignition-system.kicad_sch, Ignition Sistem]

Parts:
AOD4184A1: NMOS; TO-252-2
BLED1: LED; LED_0805_2012Metric
C1, C2: 10uf; C_0805_2012Metric
CHRG1: LED; LED_0805_2012Metric
Display1-SSD1306: Conn_01x04; PinHeader_1x04_P2.54mm_Vertical
IGNITOR1: Screw_Terminal_01x02; TerminalBlock_MaiXu_MX126-5.0-02P_1x02_P5.00mm
InBatt1: Conn_01x02; JST_PH_S2B-PH-K_1x02_P2.00mm_Horizontal
LORA-Sx1278(A)1, LORA-Sx1278(B)1: Conn_01x08; PinHeader_1x08_P2.54mm_Vertical
ModuloDeCarga1: TP4056-42-ESOP8; SOIC-8-1EP_3.9x4.9mm_P1.27mm_EP2.41x3.3mm_ThermalVias
R1, R2, R3: 330; R_0805_2012Metric
R4: 2.2k; R_0805_2012Metric
R5, R6, R7: 10k; R_0805_2012Metric
R8, R9: 1k; R_0805_2012Metric
R11: 220; R_0805_2012Metric
RLED1: LED; LED_0805_2012Metric
RaspberryPi_Pico1-RP2040: RaspberryPi_Pico; RaspberryPi_Pico_Common_Unspecified
STDBY1: LED; LED_0805_2012Metric
SW1: SW_Push; JST_PH_S2B-PH-K_1x02_P2.00mm_Horizontal
SW2, SW3: SW_SPDT; SW_E-Switch_EG1224_SPDT_Angled
TH1: NTC 10k B3950; JST_PH_S2B-PH-K_1x02_P2.00mm_Horizontal
YLED1: LED; LED_0805_2012Metric

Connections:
3V3: Display1-SSD1306.3, LORA-Sx1278(A)1.3, RaspberryPi_Pico1-RP2040.36 (3V3)
ADC_Bateria: R5.2, R6.1, RaspberryPi_Pico1-RP2040.31 (GPIO26_ADC0)
BTN_FIRE: RaspberryPi_Pico1-RP2040.17 (GPIO13), SW1.1
CHRG: ModuloDeCarga1.7 (~CHRG), R9.1
DIO0: LORA-Sx1278(A)1.5, RaspberryPi_Pico1-RP2040.27 (GPIO21)
GND: AOD4184A1.3 (S), BLED1.1 (K), C1.2, C2.2, Display1-SSD1306.4, InBatt1.2, LORA-Sx1278(A)1.1, LORA-Sx1278(A)1.2, LORA-Sx1278(B)1.1, LORA-Sx1278(B)1.8, ModuloDeCarga1.3 (GND), ModuloDeCarga1.9 (EPAD), R4.2, R6.2, R7.2, RLED1.1 (K), RaspberryPi_Pico1-RP2040.3 (GND), RaspberryPi_Pico1-RP2040.8 (GND), RaspberryPi_Pico1-RP2040.13 (GND), RaspberryPi_Pico1-RP2040.18 (GND), RaspberryPi_Pico1-RP2040.23 (GND), RaspberryPi_Pico1-RP2040.28 (GND), RaspberryPi_Pico1-RP2040.38 (GND), SW1.2, SW2.3 (C), TH1.2, YLED1.1 (K)
IGNITION_GATE: R11.1, RaspberryPi_Pico1-RP2040.20 (GPIO15)
LED_ARMADO: R3.2, RaspberryPi_Pico1-RP2040.16 (GPIO12)
LED_LINK: R1.2, RaspberryPi_Pico1-RP2040.14 (GPIO10)
LED_MODO: R2.2, RaspberryPi_Pico1-RP2040.15 (GPIO11)
MISO: LORA-Sx1278(B)1.4, RaspberryPi_Pico1-RP2040.21 (GPIO16)
MOSI: LORA-Sx1278(B)1.3, RaspberryPi_Pico1-RP2040.25 (GPIO19)
NSS: LORA-Sx1278(B)1.2, RaspberryPi_Pico1-RP2040.22 (GPIO17)
unnamed: AOD4184A1.1 (D), IGNITOR1.2
unnamed: AOD4184A1.2 (G), R7.1, R11.2
unnamed: BLED1.2 (A), R1.1
unnamed: CHRG1.1 (K), R9.2
unnamed: IGNITOR1.1, SW2.2 (B)
unnamed: C1.1, InBatt1.1, ModuloDeCarga1.5 (BAT), SW3.1 (A)
unnamed: ModuloDeCarga1.2 (PROG), R4.1
unnamed: ModuloDeCarga1.1 (TEMP), TH1.1
unnamed: R3.1, RLED1.2 (A)
unnamed: R8.2, STDBY1.1 (K)
unnamed: R2.1, YLED1.2 (A)
RST: LORA-Sx1278(A)1.4, RaspberryPi_Pico1-RP2040.26 (GPIO20)
SCK: LORA-Sx1278(B)1.5, RaspberryPi_Pico1-RP2040.24 (GPIO18)
SCL: Display1-SSD1306.2, RaspberryPi_Pico1-RP2040.7 (GPIO5)
SDA: Display1-SSD1306.1, RaspberryPi_Pico1-RP2040.6 (GPIO4)
STDBY: ModuloDeCarga1.6 (~STDBY), R8.1
VBUS: C2.1, CHRG1.2 (A), ModuloDeCarga1.4 (V_{CC}), ModuloDeCarga1.8 (CE), RaspberryPi_Pico1-RP2040.40 (VBUS), STDBY1.2 (A)
VSYS: R5.1, RaspberryPi_Pico1-RP2040.39 (VSYS), SW2.1 (A), SW3.2 (B)

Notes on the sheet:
Radiofrequency Stage
Interface stage
Computer Stage
Power Stage
Ignition Stage

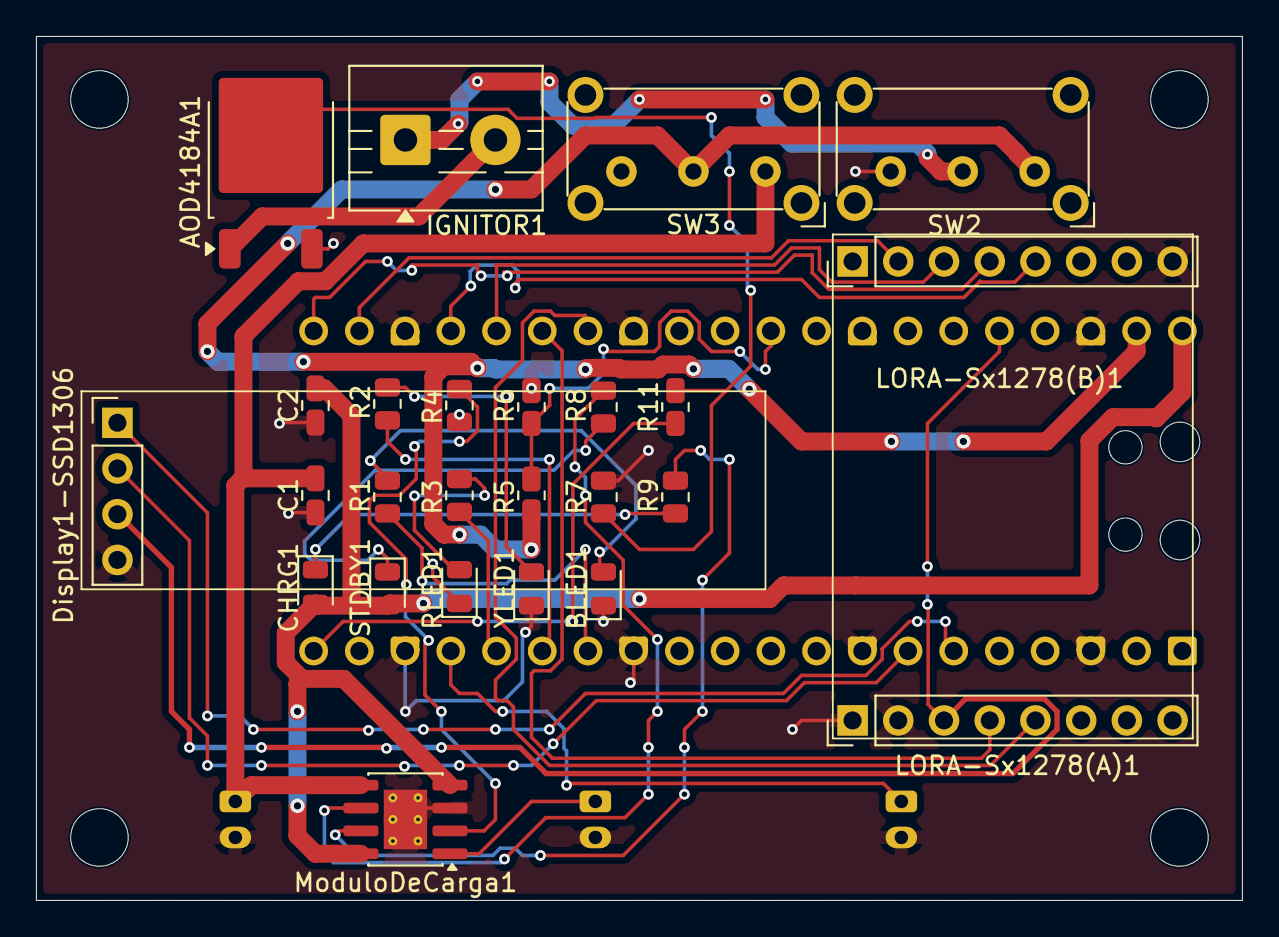
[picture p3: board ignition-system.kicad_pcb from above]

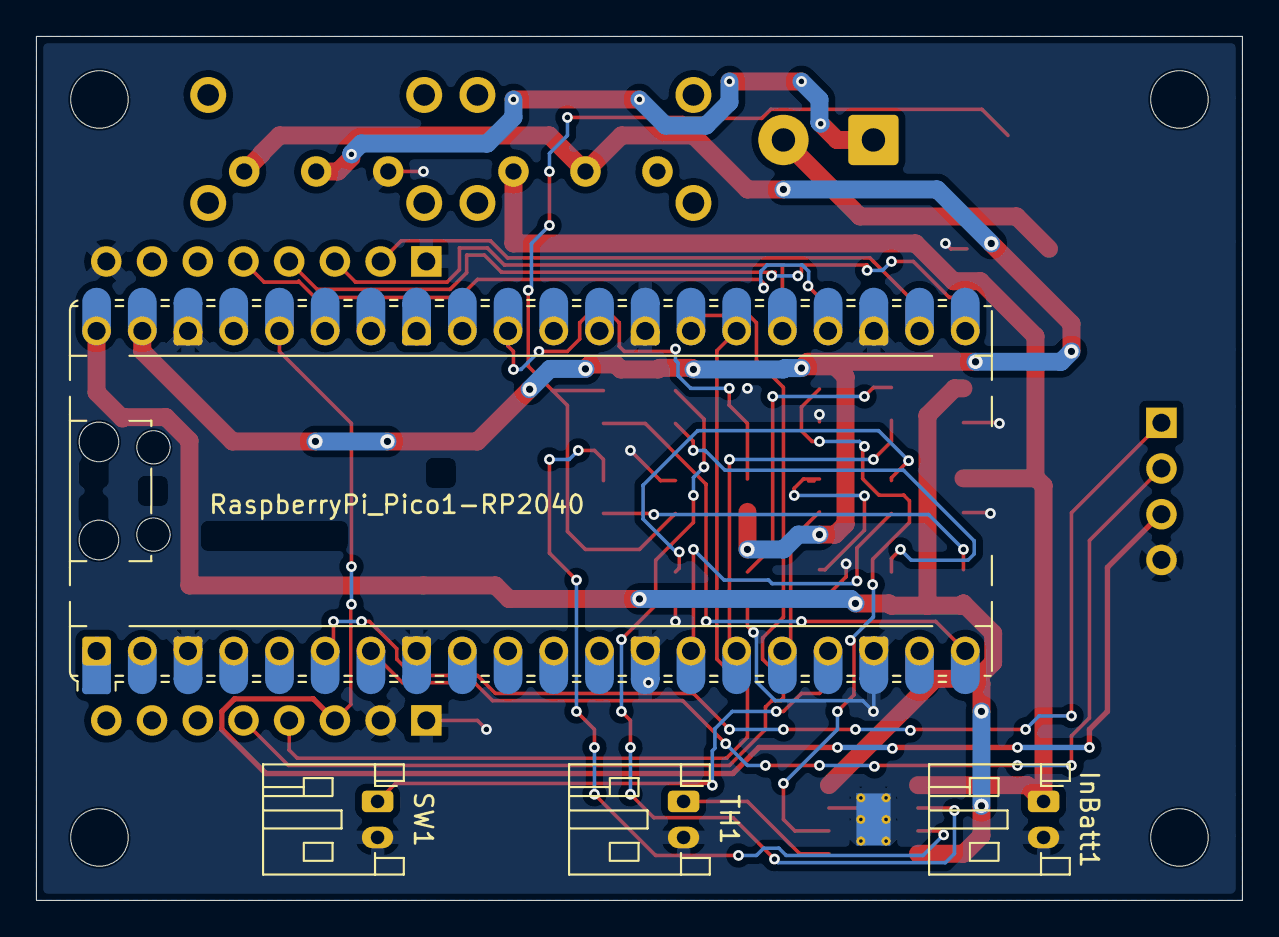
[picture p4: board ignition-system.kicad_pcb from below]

Board: 2 copper layers, 67.0 x 48.0 mm, 29 parts (4 on the bottom side), 31 nets.

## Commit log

2026-05-09 docs: actualizacion de README para el nuevo sistema RP2040
2026-05-09 feat: añadir componentes al esquematico y modelo spice a NMOS
    [ignition-system.kicad_pcb, ignition-system.kicad_sch]
2026-05-09 feat: nuevos componentes y estructura con net labels
    [ignition-system.kicad_sch]
2026-07-03 fix: schematic wires & labels
    [ignition-system.kicad_sch]
2026-07-03 chore: remove kicad backup zips from tracking
2026-07-08 feat: assign footprints
    [ignition-system.kicad_sch]
2026-07-08 feat: add components on pcb editor
    [ignition-system.kicad_pcb, ignition-system.kicad_sch]
2026-08-14 fix: solve connections
    [ignition-system.kicad_pcb]
2026-08-15 chore: ignore kicad lock files
2026-08-15 fix: wire TP4056 CE to VBUS, TEMP to GND, drop DIO labels
    [ignition-system.kicad_sch]
2026-08-15 fix: wire SW2 common to ignitor, throws to VSYS and GND
    [ignition-system.kicad_sch]
2026-08-15 docs: regenerate schematic pdf with wave 1 fixes
2026-08-15 chore(update): bump inputs
    [ignition-system.kicad_sch]
2026-08-23 chore(kicad): reordenar designators de ignition-system
2026-09-02 chore(kicad): renombrar designators con chip en ignition-system
    [ignition-system.kicad_sch]
2026-09-02 docs: wave 2 in-flight y fix humano H4 para warnings erc
2026-09-02 fix: quitar stubs sueltos de vbus en chrg1 y stdby1
    [ignition-system.kicad_sch]
2026-09-02 chore(kicad): actualizar orden de used_designators en kicad_pro
2026-09-02 docs: wave 2 integrated, veredicto spice ok para rutear
2026-09-02 docs: plan wave 3 pcb ruteo con brief executor-4
2026-09-02 build: bajar min through hole a 0.2mm
2026-09-05 docs: guia manual de ruteo h6 para wave 3
2026-09-05 feat: add flags VSYS & VBUS
    [ignition-system.kicad_pcb]
2026-09-11 feat: net class power, contorno 70x50 y placement completo
    [ignition-system.kicad_pcb]
2026-09-11 chore(kicad): reorden designators del proyecto
2026-09-11 feat: continue PCB design
2026-09-16 docs: revocar h7, lora1+lora2 son el socket del modulo ra02
2026-09-16 docs: decision log de proteccion de bateria v1
2026-09-16 fix: socket ra02 con gnd de bordes y ntc al temp
    [ignition-system.kicad_pcb, ignition-system.kicad_sch]
2026-09-16 docs: h9 switch maestro sw3 en serie con bateria
2026-09-16 docs: h9 rev switch maestro al lado del consumo
2026-09-16 feat: sw3 en consumo, tp4056 fijo a bateria, pwr flag de v
    [ignition-system.kicad_pcb, ignition-system.kicad_sch]
2026-09-16 docs: regenerar pdf con socket ntc y sw3
2026-09-17 feat: ruteo pcb de ignition-system
    [ignition-system.kicad_pcb]
2026-09-17 chore(kicad): configuracion de placa en .kicad_pro
2026-09-17 chore(fab): exportar gerbers y bom para fabrica jlcpcb
    [BOM.csv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]
2026-09-17 docs: cierre de sesion waves 1-4, fab listo

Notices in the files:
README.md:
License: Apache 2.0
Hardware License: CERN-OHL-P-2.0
